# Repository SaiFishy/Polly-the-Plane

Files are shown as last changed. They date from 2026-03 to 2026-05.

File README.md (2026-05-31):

# RC UAV (Polly MK1)

Polly is a fun, high speed and manuverable RC plane made out of 3D printed lightweight PLA parts and electronic components, designed to be easily replicatable by anyone. This is a completely original project, that is inspired by modern day single seater jets. There are no store bought transmitters or recievers, electronics wise, most things are home-engineered. You can use my project by taking it out to the park, where you can enjoy the beauty of flight for an estimated time of 15 minutes! Full specifications and calculations of this plane are found in the root directory.  I decided to build this project for two reasons:

1) It is a practical way to make use of the theoretical knowledge I have learnt on aerodynamics, lift and forces acting on flying bodies.
2) It introduces me into practical electronics, something I would like to progress further with projects in the future.

Aeronautical engineering is something I would like to pursue in the future, so I thought it would be cool to make my own plane. 

# Photo Booth:

Full 3D Model of Polly:

{E690684C-77DB-487C-A40D-2138E91768BC}

Transmitter:

{6DD9E73D-3987-4DA9-92BE-4E7886154A10}

Transmitter Custom Board:

{5275EE27-3C19-4AA1-9AFF-E367AF89E6A8}

Reciever Custom Board:

{7991383E-CCE6-4D20-B02C-3E17253A64B1}

In terms of electronics, a few things are missing from the pictures above:

a) Transciever modules are to be soldered to the 7 through hole pads found on both modules

b) Joystick modules are to be soldered to the J1 and J2 pins on the Transmitter

c) A positive and negative terminal is to be soldered to the "Battery 1.5x6v" through holes, providing energy to the transmitter circuit

Another consideration for the Reciever:

 - Servos are powered via the servo pins on the Reciever
 - The Motor is connected to an external ESC, which gives energy to the Reciever circuit.

Here is a wiring diagram, representing missing electronic devices from the transmitter and reciever circuits:

Transmitter - Joysticks are soldered on to the board, same goes for the power adapter for the transciever:

{FBBC17E1-562B-4FEB-A5EE-D416031D5EBE}

Reciever - wires soldered to power adapter, which connects to main module via inserts:

{1FAE48FF-3401-4459-8045-4B942B8E1FB7}

# My BOM:

| Name | Source | Description | Link | Unit Price | Amount |
|---|---|---|---|---|---|
|NRF24L01 Module|AliExpress|Radio Communication between Ground and UAV|https://www.aliexpress.com/item/1005009253882566.html|2.59|2|
|Steel Push Rods|AliExpress|Control of Aircraft|https://www.aliexpress.com/item/1005010645116134.html|2.48|1|
|Nylon Hinge|AliExpress|Ensures safe movement of control surfaces|https://www.aliexpress.com/item/1005003378453697.html|2.11|1|
|7 Pin Header|AliExpress|For RC Transmitter and Receiver|https://www.aliexpress.com/item/1005007569841697.html|0.63|2|
|15 Pin Female Header|AliExpress|Electronic connection component for project boards|https://www.aliexpress.com/item/100501418544370.html|1.89|1|
|Propeller|Amazon|Needed to pull the aircraft through the air|https://www.amazon.co.uk/gp/product/B0FQ64833L/|7.59|1|
|AA Battery Container|AliExpress|Needed to house the six AA batteries used for the transmitter|https://www.aliexpress.com/item/1005003507045224.html|0.28|1|
|Transmitter PCB (Batch of 5)|JLCPCB|Key electronic component for Transmitter|https://jlcpcb.com/|1.04|5|
|Receiver PCB (Batch of 5)|JLCPCB|Key electronic component for Receiver|https://jlcpcb.com/|0.30|5|
|Magnets|AliExpress|Used to attach cover to transmitter|https://www.aliexpress.com/item/1005010158237241.html|2.42|1|

Total = £29.90 or $40.22 USD <3

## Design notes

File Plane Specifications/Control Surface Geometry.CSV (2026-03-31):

Feature | Dimension | Notes
Elevon Span | 270 mm | Length along the wing
Elevon Root Chord | 65 mm | Depth at the inboard side
Elevon Tip Chord | 40 mm | Depth at the outboard side
Total Elevon Area | 2.84 dm^2 | Combined for both sides
Control Authority | 13.8% | Ratio of elevon area to total wing area
Bevel Angle | 30° top / 30° bottom | Total 60° V for 30° of travel

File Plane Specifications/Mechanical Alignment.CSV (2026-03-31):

Feature | Dimension | Notes
Mean Aerodynamic Chord (MAC) | 337.62 mm | Length
MAC Leading Edge Distance | 120.86 mm | Distance from the nose to the start of the MAC
Hinge Pivot Axis | 4.83° | Hinge and Bevel angle
Servo Rotation Angle | 4.83° | servo pockets to keep pushrods straight
Control Horn Height | 15 mm to 18 mm | Vertical distance from the hinge pivot to the pushrod hole

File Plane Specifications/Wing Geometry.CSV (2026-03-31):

Feature | Dimension | Notes
Total Wingspan | 700 mm | The full distance from tip to tip.
Semi-span | 350 mm | Distance from the centerline to one wingtip.
Root Chord | 500 mm | The length of the wing where it meets the fuselage.
Tip Chord | 60 mm | The length of the wing at the very end of the span.
Leading Edge Sweep | 53.3° | The angle the front of the wing makes with the transverse axis.
Trailing Edge Sweep | 4.83° | Calculated based on the taper; this is your hinge line axis.
Total Wing Area | 20.59 dm^2 | The total surface area available for lift.

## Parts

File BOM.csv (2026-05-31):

Name | Source | Description | Link | Unit Price | Quantity | Total Price
NRF24L01 Module | AliExpress | Radio Communication between Ground and UAV | https://www.aliexpress.com/item/1005009253882566.html | 2.59 | 2 | 5.18
Steel Push Rods | AliExpress | Control of Aircraft | https://www.aliexpress.com/item/1005010645116134.html | 2.48 | 1 | 2.48
Nylon Hinge | AliExpress | Ensures safe movement of control surfaces | https://www.aliexpress.com/item/1005003378453697.html | 2.11 | 1 | 2.11
7 Pin Header | AliExpress | For RC Transmitter and Receiver | https://www.aliexpress.com/item/1005007569841697.html | 0.63 | 2 | 1.26
15 Pin Female Header | AliExpress | Electronic connection component for project boards | https://www.aliexpress.com/item/100501418544370.html | 1.89 | 1 | 1.89
Propeller | Amazon | Needed to pull the aircraft through the air | https://www.amazon.co.uk/gp/product/B0FQ64833L/ | 7.59 | 1 | 7.59
AA Battery Container | AliExpress | Needed to house the six AA batteries used for the transmitter | https://www.aliexpress.com/item/1005003507045224.html | 0.28 | 1 | 0.28
Transmitter PCB (Batch of 5) | JLCPCB | Key electronic component for Transmitter | https://jlcpcb.com/ | 1.04 | 5 | 5.2
Receiver PCB (Batch of 5) | JLCPCB | Key electronic component for Receiver | https://jlcpcb.com/ | 0.3 | 5 | 1.49
Magnets | AliExpress | Used to attach cover to transmitter | https://www.aliexpress.com/item/1005010158237241.html | 2.42 | 1 | 2.42

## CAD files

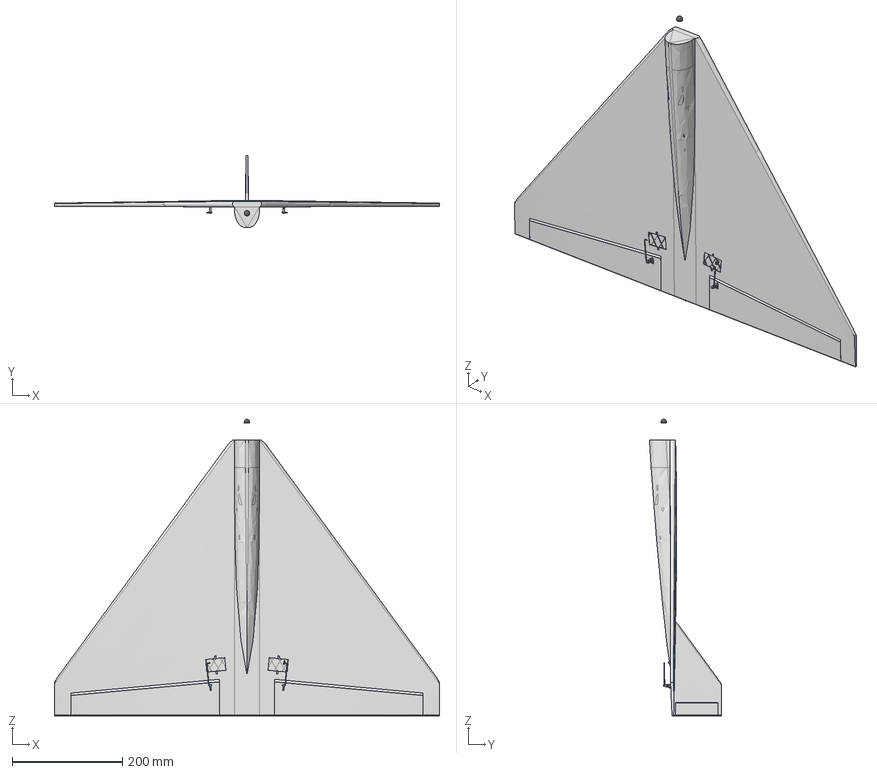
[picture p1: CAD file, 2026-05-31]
STEP Files/RC Plane Full Intergration.step
700.0 x 131.0 x 539.5 mm
PinHeader_1x03_P2.54mm_Vertical x 3
C_Disc_D5.0mm_W2.5mm_P2.50mm
RC Reciever_PCB

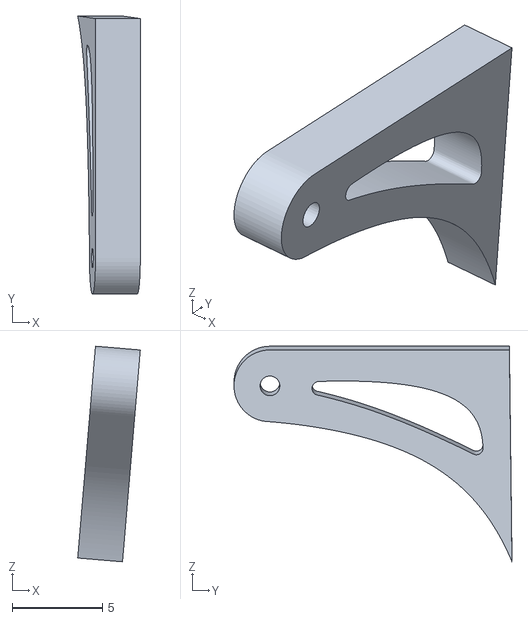
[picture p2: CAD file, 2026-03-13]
3D Printable Files (only for recreators)/Elevon Horn (PLA).stl
3.48 x 15.4 x 12.0

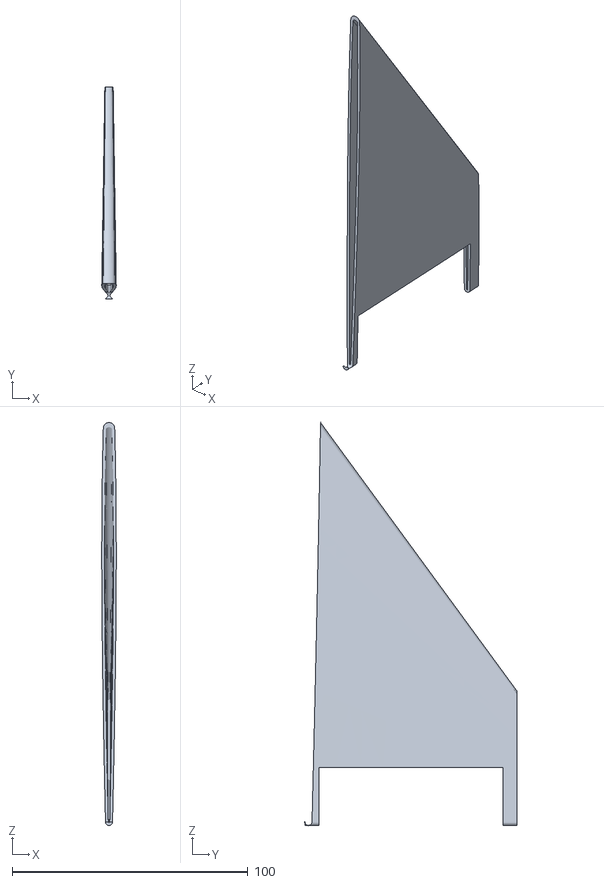
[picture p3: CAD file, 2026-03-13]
3D Printable Files (only for recreators)/Vertical Stabaliser .stl
6.17 x 90.0 x 171.0

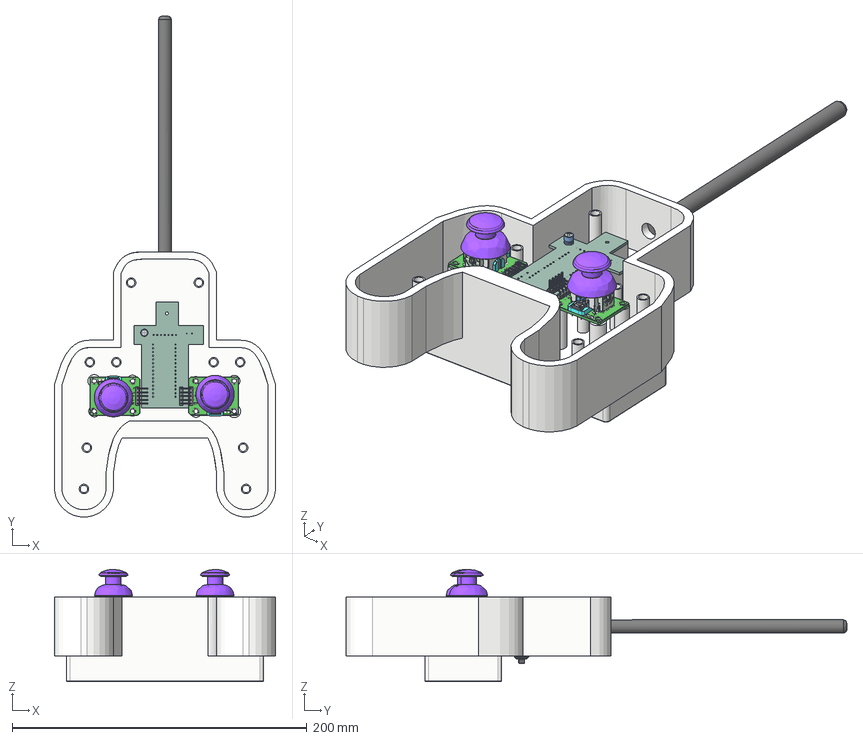
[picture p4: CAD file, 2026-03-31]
STEP Files/RC Transmitter.step
150.0 x 340.0 x 76.1 mm
CP_Radial_D5.0mm_P2.00mm
PinHeader_1x05_P2.54mm_Vertical
RC Transmitter_PCB
won95FB43B18o1cr x 2

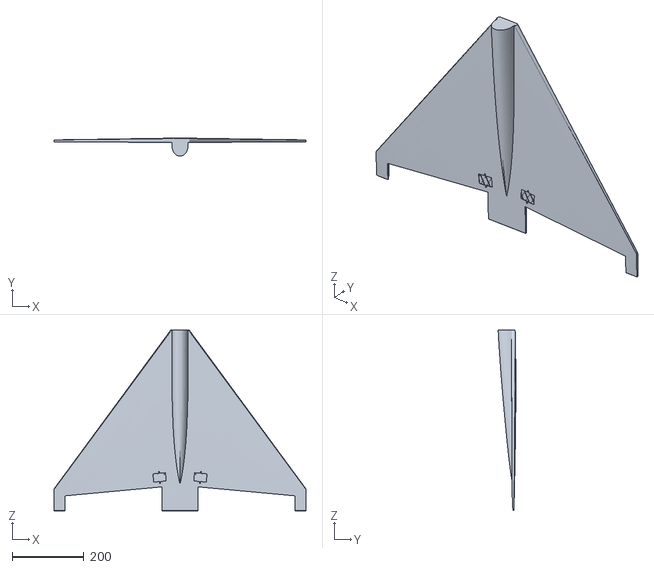
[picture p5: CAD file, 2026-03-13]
3D Printable Files (only for recreators)/Fuse + Wing.stl
700.0 x 49.4 x 501.5

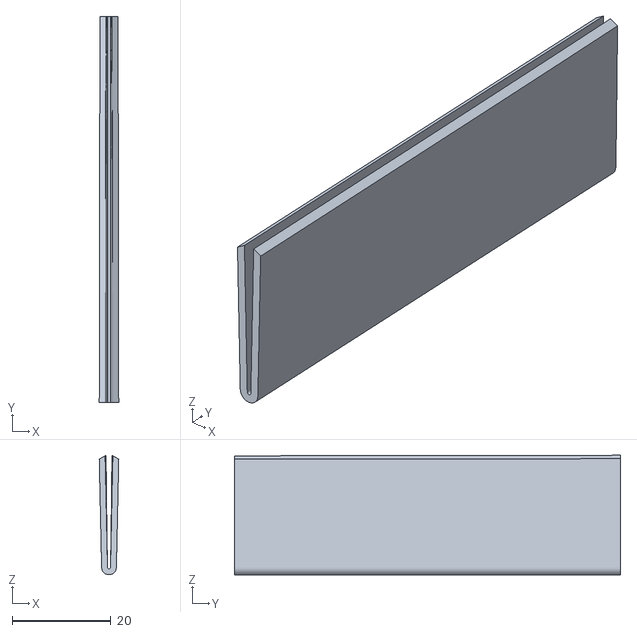
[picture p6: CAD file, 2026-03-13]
3D Printable Files (only for recreators)/VS Control Surface.stl
3.94 x 78.0 x 24.2

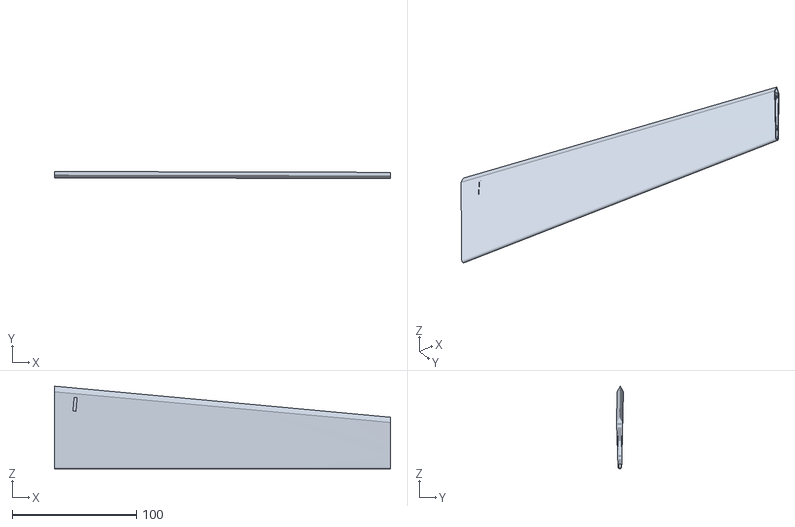
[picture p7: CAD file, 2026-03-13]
3D Printable Files (only for recreators)/Elevon.stl
270.0 x 5.60 x 66.5

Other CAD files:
Source Design Files (f3z)/RC Transmitter Source Design.f3z

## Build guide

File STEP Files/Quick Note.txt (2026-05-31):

Dear reviewer,

I have now fully intergrated the electronics of the plane into my cad files so that someone will be able to build the plane themselves. There are definitly f3d/f3z (In the source design files folder) and step files (In this folder) for both the rc transmitter and rc plane itself.

Many Thanks, Sai

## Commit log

2026-03-21 Add images for Transmitter and Receiver custom boards
2026-03-21 Replace receiver image in README
    Updated receiver wiring diagram image in README.
2026-03-21 Rename servo variables for consistency
2026-03-31 Add grant request note for plane CAD model
    Added a note regarding grant request for plane materials and electronics.
2026-03-31 Clarify grant request for plane materials and electronics
    Revised the request for grant details regarding electronic integration and components.
2026-03-31 Update BOM section in README
2026-03-31 Add link and price for LW-PLA in BOM
2026-03-31 Update BOM table with source and new items
2026-03-31 Source Design Files (f3d)
    [RC Transmitter Source Design.f3z]
2026-03-31 Add BOM file with components and pricing details
2026-03-31 Add BOM.csv with component details and pricing
    [BOM.csv]
2026-03-31 Update total cost and add transmitter PCB details
2026-03-31 Add Transmitter PCB entry to BOM
    [BOM.csv]
2026-03-31 Include total cost in BOM.csv
    Added total cost summary to BOM.
    [BOM.csv]
2026-03-31 Remove total cost line from BOM.csv
    Removed total cost line from BOM.csv.
    [BOM.csv]
2026-03-31 Total = Total = £68.65 or $90 USD
    [BOM.csv]
2026-03-31 Total = £68.56 or $90 USD
    [BOM.csv]
2026-03-31 Add wing dimensions specifications
2026-03-31 Add wing geometry specifications to CSV file
    [Wing Geometry.CSV]
2026-03-31 Fix bevel angle description formatting in CSV
    [Control Surface Geometry.CSV]
2026-03-31 Add mechanical alignment specifications CSV file
    [Mechanical Alignment.CSV]
2026-03-31 Update Control Surface Geometry.CSV
    [Control Surface Geometry.CSV]
2026-03-31 Total = £70.82 or $92 USD <3
    [BOM.csv]
2026-05-25 Remove Lipo Charger & filament from BOM
    Removed Lipo Charger entry from BOM.
2026-05-25 Remove Lipo Charger from BOM
    Removed Lipo Charger from the BOM and updated the BOM.csv file.
    [BOM.csv]
2026-05-31 Changing File names
    [RC Transmitter Source Design.f3z]
2026-05-31 Changing Files names
    [RC Plane Full Intergration.step, RC Transmitter.step]
2026-05-31 updated the bom
    [BOM.csv]
2026-05-31 Revise BOM with new components and pricing
    Updated the BOM with new items and corrected prices.
2026-05-31 Refactor BOM table to Markdown format
    Updated the BOM table format to Markdown for better readability.
